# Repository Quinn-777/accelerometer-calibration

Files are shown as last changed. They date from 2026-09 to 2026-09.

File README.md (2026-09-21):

# accelerometer-calibration

Calibrating a low-cost MEMS accelerometer (MPU-9250/6500 series) against
references that do not depend on any other sensor.

- **Phase 1 — static (done).** Six-position calibration using gravity as the
  reference, checked independently at arbitrary tilts.
- **Phase 2 — dynamic (not started).** A Scotch-yoke shake table producing
  sinusoidal motion of known amplitude and frequency, to measure frequency
  response.

## Why

This project grew out of
[ccs-seismicity-screener](https://github.com/Quinn-777/ccs-seismicity-screener),
a screening framework for induced-seismicity risk at CO₂ storage sites. That
framework was checked against the monitoring records of three real projects,
but it took those records as given. Every one of them came from an instrument
with its own reference and its own error. This repository is an attempt to see,
hands-on, how a raw sensor reading becomes a number that can be trusted.

## Status

- [x] Sensor wired and communicating (I2C address 0x68)
- [x] Fit test printed and iterated
- [x] Calibration cube printed and inspected
- [x] Six-position static calibration
- [x] Independent check at arbitrary orientations
- [ ] Phase 2: shake table

## Phase 1: static calibration against gravity

### Method

At rest, an accelerometer reads 1 g along whichever direction points up. The
sensor is bolted inside a printed cube, and the cube is set on each of its six
faces in turn, so every sensor axis sees +1 g once and −1 g once. For each
axis, the midpoint of the two readings is the zero offset and half their
difference is the scale factor. No angle has to be measured; the method only
needs the cube's faces to be square.

The check is independent of the fit: gravity is 1 g in every orientation, so
after calibration √(ax² + ay² + az²) must come out at 1.000 g at any tilt,
including tilts that played no part in the calibration.

### Result

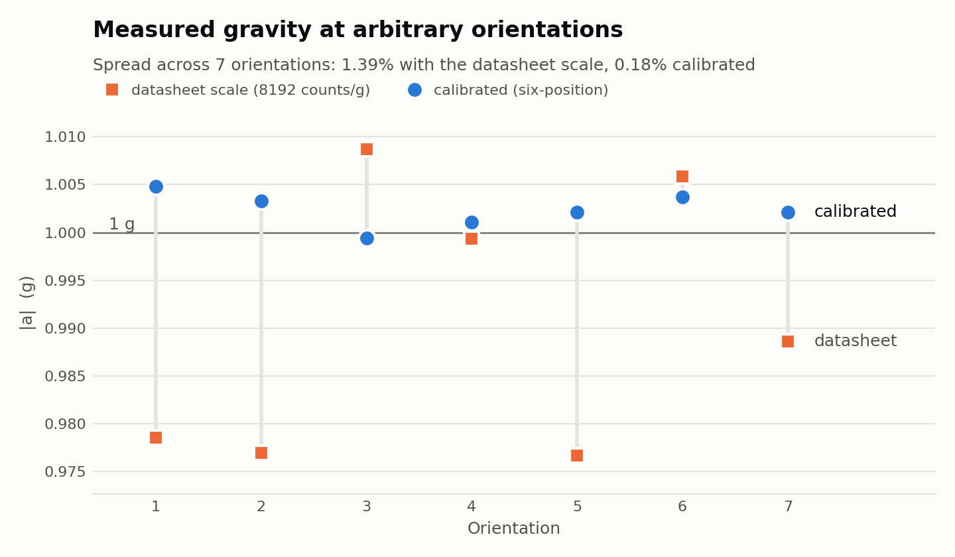
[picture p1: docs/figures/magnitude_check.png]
Measured gravity at arbitrary orientations


| Axis | Zero offset | Scale factor | vs datasheet (8192 counts/g) |
|---|---|---|---|
| X | −192 counts (−0.023 g) | 8182 counts/g | −0.12% |
| Y | +57 counts (+0.007 g) | 8217 counts/g | +0.31% |
| Z | +9 counts (+0.001 g) | 8054 counts/g | −1.69% |

Standard error about ±7 counts per value.

At seven orientations not used in the fit:

| | Datasheet scale | Calibrated |
|---|---|---|
| Spread in \|a\| | 1.39% | 0.18% |
| Worst case | 2.3% from 1 g | 0.48% from 1 g |

Only the Z axis departs noticeably from the datasheet value. Because each axis
has its own error, the uncalibrated error changes with orientation (from −2.3%
to +0.9%), so no single correction factor could remove it.

### Supporting checks

- **Out-of-sample readings.** Three Z-axis readings taken before the screws
  were re-tightened were left out of the fit. Their magnitude is 1.3–1.6% low
  with the datasheet scale and 1.001–1.004 g with the calibration.
- **Axis mapping.** Sensor +X points along cube −Y, +Y along cube −X, and +Z
  along cube −Z (the board is mounted chip-side down). Sensor X therefore runs
  along the board's short edge, which matches the silkscreen.
- **Mounting angles.** Each rotation of the board relative to the cube appears
  in two different position pairs, and the two estimates agree:

  | Rotation | Estimate 1 | Estimate 2 |
  |---|---|---|
  | About the line through the mounting holes | 3.10° | 3.32° |
  | In the board plane | 1.07° | 1.12° |
  | About the remaining axis | 0.33° | 0.48° |

  The tilt leaves the offsets unchanged and biases the X and Z scale factors low
  by 0.15–0.19%. That bias predicts calibrated magnitudes slightly above 1 g,
  which the arbitrary-orientation check then showed (mean 1.0024 g). A refit
  that forces |a| = 1 g at every calibration position removes it (mean 1.0013 g).

## Hardware

| Item | Detail |
|---|---|
| Sensor | MPU-9250/6500/9255 breakout, GY-9250 style, about 25 × 15 mm |
| Controller | Arduino Mega 2560 |
| Calibration cube | 50 mm PLA cube, printed on an Elegoo Neptune 3 Pro; sensor sits chip-side down in a 30 mm deep well |
| Fasteners | M2 × 10 screws; M2 nuts as 1.6 mm spacers under the board |

Wiring:

| Sensor | Mega 2560 |
|---|---|
| VCC | 5V |
| GND | GND |
| SCL | Pin 21 |
| SDA | Pin 20 |

Sensor settings: ±4 g range (AFS_SEL = 1, nominal 8192 counts/g), digital
low-pass filter 44 Hz.

## Reproducing the analysis

```
pip install -r requirements.txt
python analysis/six_position.py
```

The script holds all raw readings, prints the calibration and every check
above, and writes the figure to `docs/figures/magnitude_check.png`.

## Repository layout

```
analysis/six_position.py      calibration, cross-checks, validation, figure
docs/lab-notes.md             dated lab notes, newest first
docs/figures/                 generated figures
firmware/i2c_scan/            confirms the sensor answers at 0x68
firmware/read_raw/            streams raw counts on all three axes
hardware/fit_test.*           quick print to check the pocket and holes
hardware/calibration_cube.*   50 mm six-position calibration cube
```

## Known limitations

- Each reading is the mean of six consecutive serial-monitor lines, not a long
  average, so each value carries about ±7 counts of random error.
- Remounting repeatability is about 20–40 counts (0.003–0.005 g). This, not
  the arithmetic, limits offset accuracy.
- The board is tilted about 3.2° in its well because the edge with the pin
  header is unsupported. See the mounting angles above.
- Cube squareness was checked by measuring between opposite faces
  (49.68 mm on all three axes). That confirms size, not the angles between
  faces directly.
- Static range only: ±1 g. Linearity beyond 1 g and frequency response are
  not tested yet.
- The model is an offset and a scale factor per axis; cross-axis sensitivity
  is not modelled.
- Temperature was not recorded, and MEMS offsets drift with temperature.
- One sensor, one mounting.

## Phase 2 (planned)

A shake table driven by a stepper motor through a Scotch yoke, which turns
rotation into exactly sinusoidal motion. With the crank offset A measured by
calipers and the frequency f set by a hardware timer, the peak acceleration
A(2πf)² is known without any reference sensor. Note for the build: on this
board the sensor X axis runs along the short edge.

## Tools

Arduino IDE, OpenSCAD, ElegooSlicer, Python (NumPy, Matplotlib).

Claude (Anthropic) helped write the firmware, the OpenSCAD models and the
analysis script, and reviewed the method and results. Printing, assembly,
wiring and all measurements were done by the author.

## License

MIT

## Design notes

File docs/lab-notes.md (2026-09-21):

# Lab notes

Newest first. Raw counts are at the ±4 g range, where the datasheet gives
8192 counts per g.

## 2026-09-20 — Six-position calibration and independent check

**Z axis, first pair.** With the cube's +Z face up (chip down), the 12 Sept
reading repeated: ax −607, ay +32, az −8065. Chip up: ax +248, ay +52,
az +8063. Z scale 8059 counts/g (1.6% below datasheet), offset +4 counts.
ax held about −170 counts in both orientations (an offset) plus ±418 counts
that reversed with the flip (a tilt of about 3°).

**Re-tightened the screws and repeated.** Z scale 8054 counts/g, within 0.06%
of the first pair; offset +9. The tilt stayed at 3.1°, so it is fixed
geometry, not uneven tightening.

**All six positions** (six serial lines each):

| Axis | Offset (counts) | Offset (g) | Scale (counts/g) | vs datasheet |
|---|---|---|---|---|
| X | −192 | −0.023 | 8182 | −0.12% |
| Y | +57 | +0.007 | 8217 | +0.31% |
| Z | +9 | +0.001 | 8054 | −1.69% |

Random error about ±7 counts per value.

**Axis mapping.** Cube −Y up puts sensor X at +1 g, cube −X up puts sensor Y
at +1 g, cube −Z up puts sensor Z at +1 g. Sensor X runs along the board's
short edge and Y along the long edge, which matches the silkscreen arrows.

**Mounting angles.** Each rotation shows up in two different position pairs:

- about the line through the two mounting holes: 3.10° and 3.32°
- in the board plane: 1.07° and 1.12°
- about the remaining axis: 0.33° and 0.48°

Both mounting holes sit on the edge away from the pin header, so the header
edge is unsupported. It sits about 0.6 mm high, probably lifted by the jumper
wires. Offsets are unaffected, because the tilt cancels between opposite
faces. The X and Z scale factors come out 0.15–0.19% low; a fit that forces
|a| = 1 g at every position removes this.

An earlier explanation, the board leaning along its long edge by one nut
thickness, assumed sensor X ran along the long edge. The axis mapping showed
it does not.

**Repeatability.** Offsets estimated from different position pairs differ by
20–40 counts (X: −192, −167, −150). The same spread appears when a position
is measured again after picking the cube up, so remounting repeatability, not
the arithmetic, limits accuracy.

**Out-of-sample check.** Three Z readings taken before re-tightening (one from
12 Sept, two from earlier today) were not used in the fit. With the datasheet
scale their magnitude is 1.3–1.6% low; with the new calibration it is
1.001–1.004 g.

**Arbitrary orientations.** A cube balanced on one corner was rejected: its
readings wandered by 130–320 counts against normal noise of about 20, so it
was moving. Seven stable tilts, none used in the fit:

- datasheet scale: spread 1.39%, worst 2.3% from 1 g
- calibrated: spread 0.18%, worst 0.48%, mean 1.0024 g

One of the seven lies only 3° from a calibration position, so it is a weak
test. The calibrated values sit about 0.2% high, as the scale-factor bias
above predicts; with the |a| = 1 g fit the mean is 1.0013 g.

Lesson: when the orientation changes between lines, average the magnitudes,
not the vectors. Averaging vectors that point in different directions gives a
shorter vector.

## 2026-09-12 — Calibration cube printed; first mounted reading

Cube measured with calipers: 49.68 mm between every pair of opposite faces
(design 50.00 mm). No difference between axes. Linear shrinkage 0.64%,
consistent with the roughly 0.3 mm hole undersize seen on 9 Sept.

Sensor mounted chip-side down in the well, on M2 nuts as spacers, with
M2 × 10 screws. Cube +Z face up (chip down), six lines:
ax −569 (sd 23), ay +31 (sd 12), az −8044 (sd 32). Magnitude 8064 counts,
1.6% below nominal. az is negative because the chip faces down.

ax reads −0.069 g. That is either an offset or a tilt of about 4°. Flipping
the cube will separate the two: an offset keeps its sign, a tilt reverses it.

## 2026-09-09 — Fit test, fasteners, and a rejected foam mount

First fit-test print: the pocket was about 1 mm short along the long edge.
board_x changed from 25.0 to 26.0 mm.

Printed holes come out small: holes meant for M3 would not take an M3 screw,
only M2. Estimated shrinkage on holes: about 0.3 mm. Switched to M2 × 10
screws with M2 nuts.

The chip side of the board carries components, so it cannot sit directly on
the well floor. First tried a foam pad under it. Board resting chip-down on
the foam, 36 lines: ax +25 (sd 21), ay +112 (sd 19), az −8149 (sd 30).
Magnitude 8150 counts, 0.5% below nominal, far better than the bare-board
reading on 6 Sept, so most of that earlier error came from the board not
lying flat.

Not used as calibration data. Foam is elastic, so the board's attitude depends
on how it happens to compress, and in a vibration test it would add its own
stiffness and damping. Replaced by M2 nuts as rigid 1.6 mm spacers, which also
keep the components clear of the floor.

Noise on all three axes: about 20–30 counts sd (roughly 0.003 g).

## 2026-09-07 — Board identified; first models

Installed OpenSCAD and modelled a fit test: a 45 × 40 × 6 mm plate with the
sensor pocket and mounting holes. It prints in about 28 minutes, against 4 or
more hours for the full cube, so pocket and hole sizes can be checked cheaply.

The first model assumed a GY-521 (MPU-6050) board. Comparing it with the real
board showed an MPU-9250/6500/9255 breakout (GY-9250 style), about
25 × 15 mm, with both mounting holes along one long edge. The registers used,
the I2C address (0x68) and the ±4 g scale are the same, so the firmware and
the 6 Sept readings still hold. Model revised.

## 2026-09-06 — First contact with the sensor

Wired the sensor to an Arduino Mega 2560: VCC→5V, GND→GND, SCL→21, SDA→20.
The I2C scan found the device at 0x68 on the first try.

The first serial output was garbage: the monitor was at 9600 baud and the
sketch at 115200. Garbage output usually means a baud mismatch, not broken
code.

read_raw working. Bare board flat on the desk, chip up: ax −300, ay +40,
az +7990. Inverted: az −8120. Vector magnitude 7996 counts, 2.4% below
nominal. Z two-position estimate: offset −65 counts, scale 8055 counts/g.

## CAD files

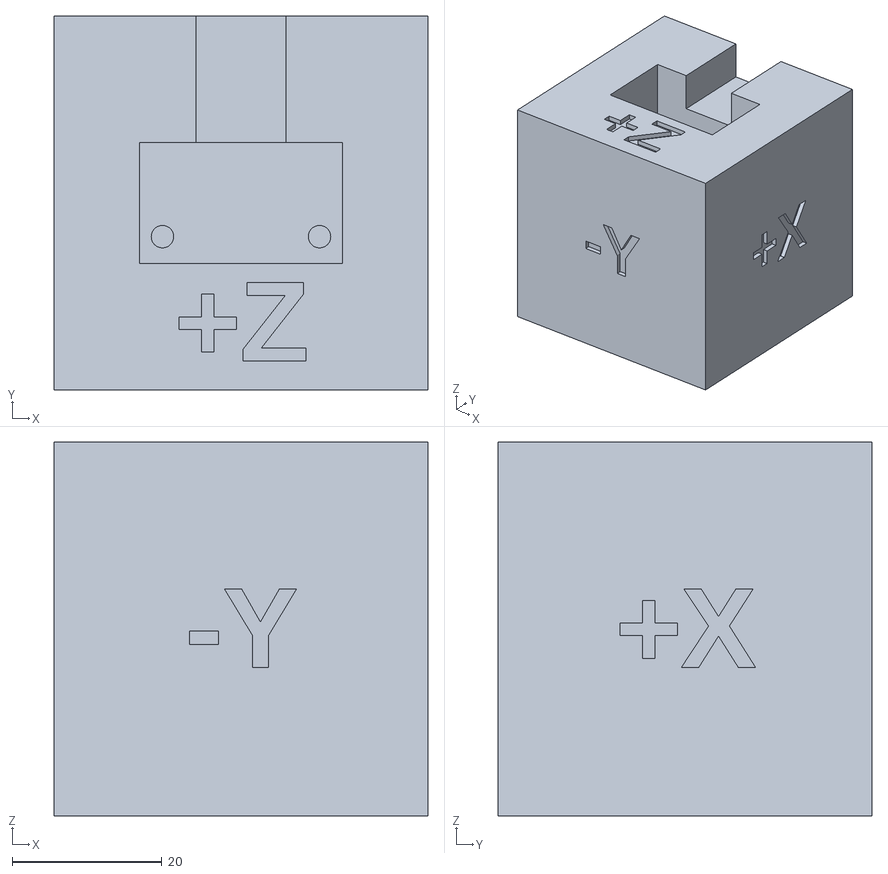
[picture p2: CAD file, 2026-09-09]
hardware/calibration_cube.stl
50.0 x 50.0 x 50.0

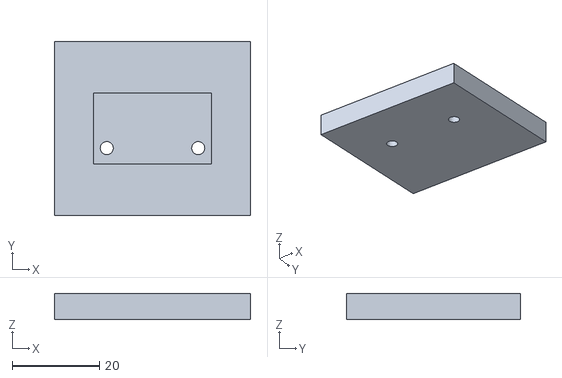
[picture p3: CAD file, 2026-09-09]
hardware/fit_test.stl
45.0 x 40.0 x 6.00

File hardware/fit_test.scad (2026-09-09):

// fit_test.scad
// Fit test for an MPU-9250/6500/9255 breakout (GY-9250 style board).
// Both mounting holes sit along one edge, near the two ends.

// ===== MEASURE THESE ON YOUR OWN BOARD =====
board_x   = 26.0;    // long edge
board_y   = 15.0;    // short edge
hole_dx   = 10.5;    // hole centre, distance from board centre along X
hole_dy   = 4.5;     // hole centre, distance from board centre along Y
                     // negative side; both holes share this offset
// ===========================================

fit       = 0.6;     // clearance around the board, per side
hole_dia  = 3;     // M3 self-taps into PLA
plate_x   = 45;
plate_y   = 40;
plate_z   = 6;
pocket_z  = 3;

$fn = 48;

difference() {
    cube([plate_x, plate_y, plate_z], center = true);

    // pocket matching the board outline
    translate([0, 0, plate_z/2 - pocket_z/2 + 0.01])
        cube([board_x + 2*fit, board_y + 2*fit, pocket_z], center = true);

    // two holes along the same edge
    for (s = [-1, 1])
        translate([s * hole_dx, -hole_dy, 0])
            cylinder(h = plate_z * 2, d = hole_dia, center = true);
}

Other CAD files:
hardware/calibration_cube.scad

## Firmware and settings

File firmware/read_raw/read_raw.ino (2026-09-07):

// read_raw.ino
// Continuously prints raw accelerometer counts on all three axes.

#include <Wire.h>

const uint8_t MPU_ADDR       = 0x68;
const uint8_t REG_PWR_MGMT   = 0x6B;
const uint8_t REG_CONFIG     = 0x1A;
const uint8_t REG_ACCEL_CFG  = 0x1C;
const uint8_t REG_ACCEL_XOUT = 0x3B;

void writeRegister(uint8_t reg, uint8_t value) {
  Wire.beginTransmission(MPU_ADDR);
  Wire.write(reg);
  Wire.write(value);
  Wire.endTransmission();
}

void setup() {
  Serial.begin(115200);
  Wire.begin();
  Wire.setClock(400000);

  writeRegister(REG_PWR_MGMT,  0x00);   // wake the chip up
  writeRegister(REG_CONFIG,    0x03);   // digital low pass filter, 44 Hz
  writeRegister(REG_ACCEL_CFG, 0x08);   // AFS_SEL = 1, range +/-4g

  Serial.println("ax\tay\taz");
}

void loop() {
  Wire.beginTransmission(MPU_ADDR);
  Wire.write(REG_ACCEL_XOUT);
  Wire.endTransmission(false);
  Wire.requestFrom((int)MPU_ADDR, 6, true);

  int16_t ax = (Wire.read() << 8) | Wire.read();
  int16_t ay = (Wire.read() << 8) | Wire.read();
  int16_t az = (Wire.read() << 8) | Wire.read();

  Serial.print(ax); Serial.print('\t');
  Serial.print(ay); Serial.print('\t');
  Serial.println(az);

  delay(200);
}

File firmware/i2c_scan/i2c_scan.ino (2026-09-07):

// i2c_scan.ino
// Scans the I2C bus and prints the address of every device found.
// Expect to find 0x68 (MPU6050 with AD0 low).

#include <Wire.h>

void setup() {
  Serial.begin(115200);
  Wire.begin();
  delay(1000);

  Serial.println("Scanning I2C bus...");
  int found = 0;

  for (uint8_t addr = 1; addr < 127; addr++) {
    Wire.beginTransmission(addr);
    if (Wire.endTransmission() == 0) {
      Serial.print("Device found at 0x");
      if (addr < 16) Serial.print("0");
      Serial.println(addr, HEX);
      found++;
    }
  }

  if (found == 0) Serial.println("No devices found. Check wiring.");
  else Serial.print("Done. Devices found: "), Serial.println(found);
}

void loop() { }

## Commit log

2026-09-07 Add I2C scanner sketch
    Confirms MPU6050 responds at 0x68
2026-09-07 Enhance README with calibration details and project context
    Expanded the README to include detailed calibration phases and project background.
2026-09-07 Add lab notes、
    sensor reads ~2% below datasheet
2026-09-07 Add fit test model for sensor pocket and hole spacing
    [fit_test.scad.stl]
2026-09-07 Add scad source; move docs to repo root
    [fit_test.scad, fit_test.stl]
2026-09-07 Fix hole layout and board dimensions for GY-9250 board
    [fit_test.scad, fit_test.stl]
2026-09-07 Correct sensor model: MPU-9250/6500/9255, not MPU-6050
2026-09-07 Add calibration cube model
    [calibration_cube.scad, calibration_cube.stl]
2026-09-07 Add calibration cube model with face labels
    [calibration_cube.scad]
2026-09-07 add rendered cube model
    [calibration_cube.stl]
2026-09-09 extend the board_x size
    [fit_test.scad]
2026-09-09 Document fit_test print measurements and fixes
    Added notes on fit_test print measurements and adjustments.
2026-09-09 Increase hole diameter for M3 self-taps
    [fit_test.scad]
2026-09-09 extend the long edge length and the hole diameter
    [fit_test.scad, fit_test.stl]
2026-09-09 Update lab notes with measurement details
    Documented first mounted measurement and noise floor observations.
2026-09-09 extend the long edge of the calibration cube
    [calibration_cube.scad, calibration_cube.stl]
2026-09-21 Enhance README with calibration details and hardware info
    Expanded the README to include detailed calibration methods, results, hardware specifications, and known limitations for the MPU-9250 accelerometer project.
2026-09-21 Implement six-position calibration for accelerometer
    Add six-position calibration script for MPU-9250/6500 accelerometer with validation.
2026-10-09 Correct sensor model and accelerometer bandwidth
2026-10-25 Add first 3 Hz capture and Y-axis calibration data
    Y-axis calibration from five tilt-corrected static captures: 8209 counts/g, offset +95 counts. 13mm_3hz_01 measured 0.923 of the predicted amplitude; the cause is still under investigation.
2026-10-28 Add landing and method pages, live USGS feed, validation figure
